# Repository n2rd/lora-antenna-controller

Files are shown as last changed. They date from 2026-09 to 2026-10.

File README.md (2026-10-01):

# LoRa Antenna Controller

A professional-grade, bidirectional LoRa-based antenna controller system for remote antenna selection and telemetry monitoring. This system is designed for amateur radio operators managing multi-element antennas.

## System Overview

The LoRa Antenna Controller consists of two components working together:

### **Shack Unit** (`lora_shack_unit/`)
- Mounted in the shack for local operator control
- Controls antenna direction via 8 pushbuttons
- Displays real-time antenna status and telemetry on OLED screen
- Supports PTT button for requesting power/SWR measurements
- Serial interface for computer-based remote control
- Hardware: Heltec WiFi LoRa 32 V3 (ESP32-S3) + SSD1306 OLED + MCP23017 GPIO expander

### **Field Unit** (`lora_field_unit/`)
- Mounted at antenna site for remote relay control
- Drives 6-channel relay module to switch antenna elements
- Monitors voltage, current, and reverse power with INA219 + ADC
- Reports telemetry back to controller via LoRa
- Supports both RemoteQTH (8-direction) and Comtek (4-direction) antenna configurations
- Hardware: Heltec WiFi LoRa 32 V3 (ESP32-S3) + INA219 power monitor

## Key Features

- **Wireless Communication**: 915 MHz LoRa (SX1262 radio)
- **Protocol**: Hygain DCU-1 compatible azimuth rotator protocol
- **Antenna Configurations**: 8-direction (RemoteQTH) or 4-direction (Comtek) via compile-time selection
- **Telemetry**: Comprehensive monitoring of voltage, current, RSSI, and reverse power
- **Reliability**: RadioLib with automatic packet retry and acknowledgment
- **Power Monitoring**: Real-time voltage/current on bus and MCU rails

## Hardware

Both units use Heltec WiFi LoRa 32 V4 boards (ESP32-S3 with SX1262).  The field-unit does not need a display.:
- **Microcontroller**: ESP32-S3 (240 MHz dual-core)
- **LoRa Radio**: SX1262 (915 MHz)
- **Power**: USB-C (microcontroller) + external 12-13.8V supply (field unit)

See individual README files in each folder for detailed hardware specifications, pinouts, and configuration options.

## Getting Started

For detailed information, see:
- **Shack Unit**: [lora_shack_unit/README.md](lora_shack_unit/README.md)
- **Field Unit**: [lora_field_unit/README.md](lora_field_unit/README.md)

Both directories contain the complete firmware code, documentation, and build instructions using PlatformIO.

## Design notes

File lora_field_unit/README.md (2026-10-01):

# LoRa Field Unit for Antenna Control

Professional-grade LoRa-based remote antenna rotator control with multi-element switching and comprehensive telemetry monitoring.

## Overview

This project implements the **Field Unit** that controls antenna rotation relays in a RemoteQTH or Comtek 4SQ antenna phasing unit. The field unit is mounted at the antenna site and provides:

- **8-direction antenna switching** (N, NE, E, SE, S, SW, W, NW) - RemoteQTH configuration
- **4-direction antenna switching** (N, E, S, W) - Comtek configuration (via compile-time selection)
- **6 independent relay outputs** for element switching
- **Real-time voltage and current monitoring** via INA219
- **Reverse power (SWR) measurement** via 12-bit ADC
- **Bidirectional LoRa communication** at 915 MHz
- **Complete telemetry reporting** (voltage, current, RSSI, etc.)

The remote unit operates in conjunction with the [lora_shack_unit](../lora_shack_unit) controller unit, receiving antenna rotation commands and returning extensive telemetry data.

## Hardware Requirements

### Field Unit
- **Microcontroller and LoRa Radio**: Heltec WiFi LoRa 32 V4 (ESP32-S3, SX1262)
- **Relay Module**: 6-channel relay interface module (GPIO controlled)
- **Voltage/Current Monitor**: Adafruit INA219 (I2C, address 0x40)
- **ADC Input**: Analog input from reverse power detector (12-bit, 0-3.3V on GPIO6)

### Required Libraries
- `jgromes/RadioLib@^7.0.0` - LoRa radio driver (SX1262)
- `adafruit/Adafruit INA219@^1.2.3` - Power monitoring

## Hardware Design

PCB design files and bill of materials are available in the `hardware/` folder:

- **[Gerber Files](hardware/field_gerbers/)** - Complete PCB design for manufacturing
  - Ready for submission to PCB manufacturers (JLCPCB, OSHPark, etc.)
  - Includes all layers for 2-layer board construction

- **[Bill of Materials (BOM)](hardware/field_bom.csv)** - Complete component list
  - CSV format compatible with most electronics suppliers
  - Includes part numbers, quantities, and reference designators
  - Use for ordering components from Digi-Key, Mouser, etc.

3D-printable enclosure files are available in the `STL/` folder:

- **[3D Enclosure Files](STL/)** - Ready-to-print case for the field unit
  - `Top.stl` - Top enclosure piece
  - `Bottom.stl` - Bottom enclosure piece
  - Recommended for SLA or FDM 3D printers with support material
  - Print orientation and parameters depend on your printer

### Assembly and Manufacturing

1. Download gerber files and submit to your PCB manufacturer
2. Review the BOM CSV file and order components
3. Use a reflow oven or soldering iron for assembly
4. Download and 3D print the STL files for the enclosure
5. See individual component datasheets for proper solder joint techniques

## Pinouts

### LoRa Radio (SX1262 via SPI)
| Function | Pin | Notes |
|---|-----|---|
| Radio CS | 8 | Chip Select |
| Radio BUSY | 13 | Busy signal |
| Radio RST | 12 | Reset |
| Radio DIO1 | 14 | Interrupt (IRQ) |
| RF FEM EN | 2 | RF Front-End Module Enable |
| RF FEM PA | 46 | RF Power Amplifier Enable |
| SPI SCLK | 12 | (Hardware SPI) |
| SPI MOSI | 11 | (Hardware SPI) |
| SPI MISO | 13 | (Hardware SPI) |

### Relay Outputs
| Relay | Pin | Purpose |
|---|-----|---|
| Relay 1 | 3 | Element 1 |
| Relay 2 | 4 | Element 2 |
| Relay 3 | 5 | Element 3 |
| Relay 4 | 33 | Element 4 |
| Relay 5/6 | 47 | Parallel relay group |
| Relay 7/8 | 48 | Parallel relay group |

### Sensors
| Function | Pin | Notes |
|---|-----|---|
| Rev Power ADC | 6 | Analog reverse power input (ADC1 Ch6) |
| I2C SDA | 41 | I2C for INA219 |
| I2C SCL | 42 | I2C for INA219 |
| Status LED | 35 | Onboard LED (LED_BUILTIN) |
| VEXT EN | 36 | Peripheral power control (active LOW) |

## Features

### Relay Configuration Tables

#### RemoteQTH - 8-Direction Configuration

| Direction | Angle | Relay Pattern | Purpose |
|---|---|---|---|
| N | 000° | 0,0,0,0,0,0 | All elements parallel |
| NE | 045° | 0,0,1,1,0,1 | Northeast phasing |
| E | 090° | 1,1,1,1,1,1 | All elements series |
| SE | 135° | 0,1,1,0,0,1 | Southeast phasing |
| S | 180° | 0,0,0,0,1,1 | Reverse configuration |
| SW | 225° | 1,1,0,0,0,1 | Southwest phasing |
| W | 270° | 1,1,1,1,0,0 | West switching |
| NW | 315° | 1,0,0,1,0,0 | Northwest phasing |

#### Comtek - 4-Direction Configuration

| Direction | Angle | Relay Pattern | Purpose |
|---|---|---|---|
| N/NE | 000-045° | 0,0,... | Pattern A |
| E/SE | 090-135° | 1,0,... | Pattern B |
| S/SW | 180-225° | 0,1,... | Pattern C |
| W/NW | 270-315° | 1,1,... | Pattern D |

**Note**: Comtek uses only 2 primary relays for 4 directions. Angles within each quadrant are mapped to the closest cardinal direction.

### Protocol

- **DCU-1 compatible** aperture rotator protocol
- **Position command**: `AP1###\r` where `###` is azimuth (000-359)
- **Position query**: `AI1;` or `AM1` requests current position
- **Power request**: Single `V` character requests reverse power telemetry
- **Auto-acknowledgment** with RadioHead reliable datagram

### Telemetry Data

Each reply packet contains complete antenna and power measurements:

```
+-------+-----+-----+-----+-----+-----+
| Type  | Dir | RSSI | Volt| Curr| Batt|
| (1)   | (3) | (5)  | (5) | (3) | (4) |
+-------+-----+-----+-----+-----+-----+
;       045   r-095 v13800 i0500 b4200
V       1250.6
```

**Position Reply Format**: `;XYZrRRRRvVVVVViIIIbBBBB`
- `;` - Position reply marker
- `XYZ` - 3-digit azimuth (000-359)
- `rRRRR` - RSSI (e.g., r-095 for -95 dBm)
- `vVVVVV` - Bus voltage in mV (e.g., v13800 = 13.8V)
- `iIII` - Bus current in mA (e.g., i0500 = 500mA)
- `bBBBB` - MCU supply voltage in mV

**Power Reply Format**: `VPPPPPP`
- `V` - Power reply marker
- `PPPPPP` - Reverse power in watts (6 chars, e.g., 1250.6W)

## Configuration

All hardware parameters are defined in `include/config.h`:

### Antenna Controller Type Selection

The phaser unit supports **two antenna controller types** selectable at compile time:

#### RemoteQTH (8-Direction) - DEFAULT
- Supports 8 antenna directions: N, NE, E, SE, S, SW, W, NW
- Most flexible configuration
- Recommended for full-featured antenna control

#### Comtek (4-Direction)
- Supports 4 main directions with combined angles
- Simpler relay switching
- Compatible with older Comtek rotators

## Quick Start with Pre-Built Binaries

Pre-compiled binaries are available in the [GitHub Releases](https://github.com/your-org/lora-antenna-controller/releases) for both RemoteQTH and Comtek configurations:

- `lora_field_unit_remoteqth.bin` - 8-direction RemoteQTH antenna controller (default)
- `lora_field_unit_comtek.bin` - 4-direction Comtek antenna controller

### Flashing with ESP Web Tools (Recommended - No Installation Required!)

1. **Download the binary** from [Releases](https://github.com/your-org/lora-antenna-controller/releases)

2. **Connect your Heltec device** via USB cable

3. **Open ESP Web Tools** in your browser:
   - Visit: https://esp.huhn.me/
   - Or use: https://web.esphome.io/

4. **Click "Connect"** and select your device's serial port from the popup

5. **Select the binary file**:
   - Click "Choose file" and select `lora_field_unit_remoteqth.bin` or `lora_field_unit_comtek.bin`

6. **Click "Program"** and wait for the flash to complete

7. **Done!** The device will reboot automatically

That's it! No command line needed.

### Building for Different Antenna Types using PlatformIO

**For RemoteQTH (default, 8-direction):**
```bash
cd lora_field_unit
pio run -t upload -e heltec_wifi_lora_32_V3
```

**For Comtek (4-direction):**
```bash
cd lora_field_unit
pio run -t upload -e heltec_wifi_lora_32_V3 -D ANTENNA_CONFIG=2
```

### Configuration at Compile Time

The antenna type is controlled via the `ANTENNA_CONFIG` define in `include/config.h`:

```cpp
#define ANTENNA_CONFIG ANTENNA_REMOTEQTH  // 1 = RemoteQTH
#define ANTENNA_CONFIG ANTENNA_COMTEK     // 2 = Comtek
```

Or via `platformio.ini`:

```ini
; RemoteQTH (default)
build_flags = -D ANTENNA_CONFIG=1

; Comtek
build_flags = -D ANTENNA_CONFIG=2
```

### Radio and Hardware Parameters

```cpp
#define SX1262_FREQ 915.0         // LoRa frequency
#define MY_ADDRESS 212            // This remote unit's address
#define CTRL_ADDRESS 211          // Controller unit address
#define INA219_I2C_ADDRESS 0x40   // Power monitor I2C address
#define REV_POWER_PIN 6           // Reverse power ADC pin
#define REV_POWER_CONVERSION_FACTOR 371.71F // ADC to power conversion
```

## Building and Uploading

### With PlatformIO

```bash
cd lora_field_unit

# Build the project
pio run -e heltec_wifi_lora_32_V3

# Upload to device
pio run -t upload -e heltec_wifi_lora_32_V3

# Monitor serial output (115200 baud)
pio device monitor -b 115200
```

### With Arduino IDE

1. Install ESP32 board definitions (via Boards Manager: "esp32")
2. Install Heltec board support (https://github.com/Heltec-Aaron-Lee/WiFi_Kit_series)
3. Select "Heltec WiFi LoRa 32(V3)" as board
4. Install required libraries:
   - RadioLib (jgromes/RadioLib)
   - Adafruit INA219
5. Upload sketch

## Installation

### At Antenna Site
1. Mount Feather M0 in weatherproof enclosure
2. Connect LoRa antenna to SMA connector
3. Wire relay module outputs to antenna controller
4. Connect INA3221 power monitor to supply bus
5. Connect reverse power detector to ADC input (A2)
6. Connect relay coils to their respective elements

### Weatherproofing
- Mount PCB in IP67 rated enclosure
- Apply conformal coating to PCB (recommended for outdoor use)
- Use shielded SMA connector for antenna
- Add moisture-absorbing desiccant packet inside enclosure

## Operation

### Startup Sequence
1. Serial output shows initialization messages
2. Radio configured and tested
3. Relays initialized to safe state (North position)
4. Onboard LED flashes to confirm ready state

### Command Processing
1. Controller sends antenna direction command
2. Phaser receives and parses command
3. Relays configured for requested direction
4. Sensors read (voltage, current, power)
5. Reply packet transmitted back to controller
6. LED flashes once per successful transmission

### Telemetry Measurements

**Voltage Monitoring (INA219)**:
- Bus voltage measurement
- MCU supply rail monitoring
- Shunt resistor: 0.10Ω

**Current Measurement**:
- Bus current range: ±3.2A (with 0.10Ω shunt)
- Calibration: Via INA219 library

**Reverse Power ADC**:
- 12-bit resolution (0-1023 counts via analogReadMilliVolts())
- Input range: 0-3.3V
- Sampling: 10-sample average with 3-top averaging
- Conversion factor: 371.71 (calibrated for detector voltage)

## Error Handling

- **Radio init failed**: Continuous LED blink, halts operation
- **No INA219**: Log error to serial, continue with zero telemetry
- **Invalid command**: Log warning, return current position
- **Send failed**: Log error, await next command

### Protocol Compliance

Implements **Yaesu DCU-1** rotator protocol for maximum compatibility:

- **Command set**: AP1###, AI1, V, ;
- **ASCII protocol**: Easy integration with existing systems
- **Binary telemetry**: Optional for future enhancement
- **Reliable delivery**: RadioHead datagram with automatic retry
- **Angle parsing**: Auto-maps requested angle to nearest supported direction

#### Angle-to-Direction Mapping

**RemoteQTH** - Direct 45° increments:
- 000° → N, 045° → NE, 090° → E, 135° → SE, etc.

**Comtek** - Quadrant-based (can accept any angle, maps to nearest quadrant):
- 000-045° → N/NE pattern
- 090-135° → E/SE pattern
- 180-225° → S/SW pattern
- 270-315° → W/NW pattern

Both configurations accept the full 0-359° angle range for maximum compatibility with existing controllers.

## Troubleshooting

### No response from phaser
1. Check LoRa antenna connector is secure
2. Verify power supply is connected (LED should indicate operation)
3. Check address settings in `config.h` match controller
4. Monitor serial output for error messages

### Relays not switching
1. Check relay module power supply (typically 12V, 1A+)
2. Verify relay coil winding voltage matches supply
3. Check GPIO pins are correctly wired to relay inputs
4. Test relay operation with DC power supply directly

### Telemetry not updating
1. Check INA219 I2C connections
3. Check address 0x40 is correct for your INA219
4. Monitor serial output for I2C init errors

### ADC reverse power readings are wrong
1. Check ADC input voltage is 0-3.3V range
2. Verify voltage divider in reverse power detector
3. Adjust `REV_POWER_CONVERSION_FACTOR` in config.h
4. Calibrate against known SWR bridge readings

## License

This project is licensed under the MIT License - see [LICENSE](LICENSE) file for details.

## Contributing

Contributions are welcome! Please follow these guidelines:

1. Fork the repository
2. Create a feature branch (`git checkout -b feature/AmazingFeature`)
3. Commit your changes (`git commit -m 'Add some AmazingFeature'`)
4. Push to the branch (`git push origin feature/AmazingFeature`)
5. Open a Pull Request

## References

- [RadioLib Documentation](https://jgromes.github.io/RadioLib/)
- [Yaesu DCU-1 Protocol](https://www.yaesu.com)
- [Heltec WiFi LoRa 32 V3 Documentation](https://docs.heltec.org/en/node/esp32/dev-board/lora/index.html)
- [Heltec GitHub](https://github.com/Heltec-Aaron-Lee/WiFi_Kit_series)
- [SX1262 LoRa Module Datasheet](https://www.semtech.com/products/wireless-rf/lora-transceivers/sx1262)
- [Adafruit INA219 Library](https://github.com/adafruit/Adafruit_INA219)
- [INA219 Power Monitor Datasheet](https://www.ti.com/lit/ds/symlink/ina219.pdf)

## Authors

- Rajiv Dewan, N2RD. rmdewan@gmail.com

## Acknowledgments

- Adafruit Industries for excellent hardware and libraries
- Mike McCauley for RadioHead library
- Hygain for DCU-1 protocol specification

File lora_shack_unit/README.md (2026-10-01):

# LoRa Antenna Controller - Shack Unit

Professional-grade LoRa-based antenna azimuth controller for remote antenna selection and telemetry monitoring from the shack.

## Overview

This project implements a **controller unit** that wirelessly controls antenna rotation via LoRa radio. The controller is mounted in the shack and provides:

- **8-direction antenna control** (N, NE, E, SE, S, SW, W, NW)
- **Real-time telemetry display** on SSD1306 OLED screen
- **Button interface** for quick direction selection (via MCP23017 GPIO expander)
- **PTT button** for requesting reverse power / telemetry
- **Serial interface** for computer control
- **Link quality monitoring** with RSSI display
- **Bidirectional LoRa communication** at 915 MHz

The controller works in tandem with the [lora_field_unit](../lora_field_unit) remote unit, which drives the relay switches to select antenna elements.

## Hardware Requirements

### Controller Unit
- **Microcontroller and LoRa Radio**: Heltec WiFi LoRa 32 V3 (ESP32-S3, SX1262)
- **OLED Display**: SSD1306 128×64 pixel display (built-in, on dedicated I2C bus)
- **GPIO Expander**: MCP23017 I2C to digital I/O (for buttons and LEDs)
- **Buttons**: 8 pushbuttons for direction selection (on MCP23017)
- **LEDs**: 8 LEDs for direction indication (on MCP23017)
- **PTT Switch**: Momentary pushbutton (GPIO3 on ESP32)

### Required Libraries
- `jgromes/RadioLib@^7.0.0` - LoRa radio driver (SX1262)
- `adafruit/Adafruit MCP23017 Arduino Library@^2.3.2` - GPIO expander
- `olikraus/U8g2@^2.35.9` - OLED display driver (SSD1306)

## Hardware Design

PCB design files and bill of materials are available in the `hardware/` folder:

- **[Gerber Files](hardware/shack_gerbers/)** - Complete PCB design for manufacturing
  - Ready for submission to PCB manufacturers (JLCPCB, OSHPark, etc.)
  - Includes all layers for 2-layer board construction

- **[Bill of Materials (BOM)](hardware/shack_bom.csv)** - Complete component list
  - CSV format compatible with most electronics suppliers
  - Includes part numbers, quantities, and reference designators
  - Use for ordering components from Digi-Key, Mouser, etc.

3D-printable enclosure files are available in the `STL/` folder:

- **[3D Enclosure Files](STL/)** - Ready-to-print case for the shack controller
  - `Top.stl` - Top enclosure piece
  - `Bottom.stl` - Bottom enclosure piece
  - `Bracket.stl` - Mount bracket for desk/shelf mounting
  - Recommended for SLA or FDM 3D printers with support material
  - Print orientation and parameters depend on your printer

### Assembly and Manufacturing

1. Download gerber files and submit to your PCB manufacturer
2. Review the BOM CSV file and order components
3. Use a reflow oven or soldering iron for assembly
4. Download and 3D print the STL files for the enclosure and bracket
5. See individual component datasheets for proper solder joint techniques

## Pinouts

### LoRa Radio (SX1262 via SPI)
| Function | Pin | Notes |
|---|-----|---|
| Radio CS | 8 | Chip Select |
| Radio BUSY | 13 | Busy signal |
| Radio RST | 12 | Reset |
| Radio DIO1 | 14 | Interrupt (IRQ) |
| RF FEM EN | 2 | RF Front-End Module Enable |
| RF FEM PA | 46 | RF Power Amplifier Enable |
| SPI SCLK | 12 | (Hardware SPI) |
| SPI MOSI | 11 | (Hardware SPI) |
| SPI MISO | 13 | (Hardware SPI) |

### Display and I2C
| Function | Pin | Notes |
|---|-----|---|
| OLED SDA | 17 | I2C1 (built-in display) |
| OLED SCL | 18 | I2C1 (built-in display) |
| OLED RST | 21 | Reset pin |
| MCP SDA | 41 | I2C (external GPIO expander) |
| MCP SCL | 42 | I2C (external GPIO expander) |

### Buttons and User Input
| Function | Pin | Notes |
|---|-----|---|
| PTT Button | 3 | GPIO3, INPUT_PULLUP, active LOW |
| Direction Buttons | MCP23017 0-7 | 8 buttons on GPIO expander ports A |
| Direction LEDs | MCP23017 8-15 | 8 LEDs on GPIO expander ports B |

### Power and Control
| Function | Pin | Notes |
|---|-----|---|
| Status LED | 35 | Onboard LED (LED_BUILTIN) |
| VEXT EN | 36 | Peripheral power control (active LOW) |

## Features

### Protocol
- **DCU-1 compatible** aperture command format
- **Position format**: `AP1###\r` where `###` is azimuth (000-359)
- **PTT format**: Single character `V` requests telemetry
- **Automatic acknowledgment** with RadioHead reliable datagram

### Display Output
Shows real-time antenna telemetry:
```
Rev 12.5 W
RSSI: -095 dBm
Pos: 045
Dir: NE
```

### Serial Interface
- Baud rate: **115200** (USB CDC on ESP32-S3)
- Can accept direction names: `N`, `NE`, `E`, `SE`, `S`, `SW`, `W`, `NW`
- Can accept angle values: `0`, `45`, `90`, `135`, `180`, `225`, `270`, `315`

### User Interactions
1. **Push buttons (0-7)**: Select antenna direction, sends command immediately
2. **PTT button**: Request reverse power telemetry from remote shack
3. **Serial input**: Remote computer control via RS-232 interface

## Configuration

All hardware pins and protocol parameters are defined in `include/config.h`:

```cpp
#define SX1262_FREQ 915.0       // LoRa frequency
#define MY_ADDRESS 211          // This controller's address
#define DEST_ADDRESS 212        // Remote field unit address
#define MCP_I2C_ADDRESS 0x20    // MCP23017 I2C address
#define OLED_I2C_ADDRESS 0x3C   // SSD1306 OLED I2C address
#define PTT_PIN 3               // PTT button input (GPIO3)
```

## Quick Start with Pre-Built Binaries

Pre-compiled binaries are available in the [GitHub Releases](https://github.com/your-org/lora-antenna-controller/releases):

- `lora_shack_unit.bin` - Complete shack controller unit firmware

### Flashing with ESP Web Tools (Recommended - No Installation Required!)

1. **Download the binary** from [Releases](https://github.com/your-org/lora-antenna-controller/releases)

2. **Connect your Heltec device** via USB cable

3. **Open ESP Web Tools** in your browser:
   - Visit: https://esp.huhn.me/
   - Or use: https://web.esphome.io/

4. **Click "Connect"** and select your device's serial port from the popup

5. **Select the binary file**:
   - Click "Choose file" and select `lora_shack_unit.bin`

6. **Click "Program"** and wait for the flash to complete

7. **Done!** The device will reboot automatically

That's it! No command line needed.

## Building and Uploading

### With PlatformIO (Recommended)

```bash
cd lora_shack_unit

# Build the project
pio run -e heltec_wifi_lora_32_V3

# Upload to device
pio run -t upload -e heltec_wifi_lora_32_V3

# Monitor serial output (115200 baud)
pio device monitor -b 115200
```

### With Arduino IDE

1. Install ESP32 board definitions (via Boards Manager: "esp32")
2. Install Heltec board support (https://github.com/Heltec-Aaron-Lee/WiFi_Kit_series)
3. Select "Heltec WiFi LoRa 32(V3)" as board
4. Install required libraries:
   - RadioLib (jgromes/RadioLib)
   - U8g2 (olikraus/U8g2)
   - Adafruit MCP23017 Arduino Library
5. Upload sketch

## Troubleshooting

### No communication with field unit
1. Check LoRa antenna is properly connected to SMA connector
2. Test radio with debug output enabled (`#define DEBUG 1` in config.h)
3. Check address settings in `config.h` match field unit (MY_ADDRESS=211, DEST_ADDRESS=212)
4. Verify frequency matches: 915.0 MHz

### Display not showing anything
1. Check OLED display is properly seated
2. Verify I2C address is 0x3C (SSD1306)
3. Enable debug output to monitor I2C initialization errors

### Buttons not responding
1. Check MCP23017 is properly seated on breadboard or module
2. Verify I2C address matches config (0x20 default)
3. Check button wiring to MCP pins (should be between pin and GND)
4. Verify MCP I2C address via I2C scanner if issues persist

### PTT button not working
1. Verify GPIO3 is not being used elsewhere
2. Check button wiring (pin 3 to GND for activation)
3. Ensure INPUT_PULLUP is enabled
4. Test with serial debug enabled

### Startup Sequence
1. Serial output shows initialization messages
2. Radio configured and tested
3. Display shows "READY!"
4. Direction LED turns on (matches current antenna position)

### Normal Operation
1. Press a direction button to rotate antenna
2. LED blinks to confirm command transmission
3. Display updates with current direction and telemetry
4. Press PTT to request reverse power reading
5. Display shows reverse power reading from remote unit

### Error Handling
- **Radio init failed**: LED blinks continuously
- **No reply from phaser**: "No Reply!" displays on OLED
- **Send failed**: "Send Failed!" displays on OLED

## Protocol Details

### Command Types

| Command | Format | Response | Purpose |
|---|---|---|---|
| Set direction | AP1###\r | ;XYZr... | Set antenna azimuth and execute |
| Position query | I1; | ;XYZr... | Request current antenna position |
| Power query | V | VPPPPPP | Request reverse power reading |

### Telemetry Data Returned

Position reply includes:
- Antenna azimuth (000-359°)
- Transmit RSSI (signal strength out, dBm)
- Reverse power measurement (W)
- Bus voltage and current
- MCU supply voltage

## References

- [RadioLib Documentation](https://jgromes.github.io/RadioLib/)
- [Yaesu DCU-1 Rotator Protocol](https://www.yaesu.com)
- [Heltec WiFi LoRa 32 V3 Documentation](https://docs.heltec.org/en/node/esp32/dev-board/lora/index.html)
- [Heltec GitHub](https://github.com/Heltec-Aaron-Lee/WiFi_Kit_series)
- [SX1262 LoRa Module Datasheet](https://www.semtech.com/products/wireless-rf/lora-transceivers/sx1262)
- [MCP23017 I/O Expander Datasheet](https://ww1.microchip.com/en-US/product/mcp23017)
- [U8g2 Library](https://github.com/olikraus/u8g2)
- [Adafruit MCP23017 Arduino Library](https://github.com/adafruit/Adafruit-MCP23017-Arduino-Library)

## Authors

- Rajiv Dewan, N2RD rmdewan@gmail.com

## Acknowledgments

- Adafruit Industries for excellent hardware and libraries
- RadioHead Library by Mike McCauley
- Yaesu Corporation for the DCU-1 protocol specification

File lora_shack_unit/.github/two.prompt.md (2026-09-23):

There are two differnt commands that the controller sends to the phaser: a direction command a power command.

The responses from the phaser are different for the two commands.  

The display shows the results of both the commands.  When displaying the results of the direction command, it shoudl reuse the previous displayed value of the power command.  And vice versa, when displaying the results of the power command, it should reuse the previous displayed value of the direction command.

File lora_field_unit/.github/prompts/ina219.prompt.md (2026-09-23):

I want to transition from using the INA3221 sensor to the INA219 sensor for my project. Can you help me with the necessary changes I need to make in my code and hardware setup to accommodate this transition?

The INA3221 is a multiport device and I was using it to measure (1) the bus voltage and current and (2) mcu voltage and current. 

INA 219 is a single channel device.  I will only be measuring bus voltage and current.  I will drop the measurement of mcu voltage and current.  Also, this will not be sent in the payload to the server.  I will only be sending bus voltage and current in the payload.

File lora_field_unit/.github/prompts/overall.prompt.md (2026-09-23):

I have a pair of related projects: lora_phaser_heltec and lora_cont_heltec.  They communicate with each other using LoRa.  

The lora_cont_heltec project is the controller.  It accepts input from the buttons and USB serial port and sends commands using lora to lora_phaser_heltec ih the field.

The lora_phaser_heltec processes the commands and sends a packet of information back to the controller.

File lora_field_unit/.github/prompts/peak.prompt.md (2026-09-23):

I want improve the reverse power measurement as the RF power is applied in pulses as short as 24 mS (morse code dit at 50WPM).  Here are some ideas:

1.  Use the calibrated ADC measurement on ESP32-S3 to measure the reverse power more accurately.  On the ESP32S3 this is done using analogReadMilliVolts() instead of analogRead().  This will give a more accurate measurement of the voltage on the reverse power pin, which can be used to calculate the reverse power more accurately.
2. There is a voltage divider and to adjust for this we need to multiply the measured voltage by 169.86. This will be the new calibration factor for the reverse power measurement.
3. Since the power is pulsed, averaging is not helpful.  An yet there is a lot of noise in the measurement. We need to find a statistic to get a better estimate of the peak without the noise.  What would be a good method?

One approach is the following:
Make 10 measurements, 10mS apart.  Take the average of just the top 3 values.  This will give us a better estimate of the peak power while reducing the impact of noise.  The 10mS interval is chosen to capture the short pulses of RF power, and averaging the top 3 measurements helps to mitigate any outliers caused by noise.

Any other ideas?

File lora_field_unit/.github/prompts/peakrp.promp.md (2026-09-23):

The phaser sends back peak reverse power to the controller.  

I would like to implement a peak-hold feature for this value.

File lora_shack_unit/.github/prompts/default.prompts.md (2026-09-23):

When the unit boots up, it should default to DIR_NE and that LED should be lit.  Instead, it seems to go an random state (different one each time).This is likely an initialization error that needs to be fixed.

After a button is pressed, the controller waits for a reply and then uses the direction in the apply to do the following:

1. It should blink that LED that corresponds to the reply twice and then leaves it lit. (0.5 sec cycle for blinking)
2. It should show the direction in the reply on the LED.

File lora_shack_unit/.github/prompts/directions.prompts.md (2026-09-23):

Somehow, my files have gotten the directions, and numbering mixed up.

Here is what I want:
// inits for the controller unit
// NE has all relays off and is perfect for default
int last_button = 0;  //initialize last button pressed, default to NE

//directions
#define NE 0
#define E  1
#define SE 2
#define S  3
#define SW 4
#define W  5
#define NW 6
#define N  7

int direction = 0;  //current position

And in the phaser:

//array of relay status for each position
boolean relay[8][6]{ //remoteqth 
  {LOW,  LOW,  LOW,  LOW,  LOW,  LOW},  //NE 0
  {LOW,  LOW,  HIGH, HIGH, LOW,  HIGH}, //E 1
  {HIGH, HIGH, HIGH, HIGH, HIGH, HIGH}, //SE 2
  {LOW,  HIGH, HIGH, LOW,  LOW,  HIGH}, //S 3
  {LOW,  LOW,  LOW,  LOW,  HIGH, HIGH}, //SW 4
  {HIGH, HIGH, LOW,  LOW,  LOW,  HIGH}, //W 5
  {HIGH, HIGH, HIGH,  HIGH, LOW,  LOW},  //NW 6
  {HIGH, LOW,  LOW,  HIGH, LOW,  LOW}   //N 7
};

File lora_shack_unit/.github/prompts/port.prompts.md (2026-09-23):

I want to port the project lora_cont_2 from using Adafruit Feather M0 with RFM95 LoRa radio to a Heltec V4.  Here are some details for the porting:

1.  I have placed a default platformio environment in platformio.ini.  It may need some modification, in particular to use the same LoRa libray as the Adafruit version.

2. We will use the pins as defined the variants.h file (part of heltec library)

3. The built in display uses I2C, with pin 17 for SDA and pin 18 for SCL.  These are already defined in the variants.h file.  It display is 128 x 64.  I would like to use it in the portrait orientation.  It uses the SSD1306 driver.

4. We will use the default I2C already defined in variants.h SDA (4) and SCL (3) pins for conntecting to the MCP23017 GPIO expander. 

5.  We will use GPIO3 (ADC1: Channel 2) cofigured with PULLUP to read the PTT status.  It is active low.

6.  I want to be able to use either board.  So we may have to put compile time conditionals for each board.

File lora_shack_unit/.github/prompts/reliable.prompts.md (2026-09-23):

Lightweight ACK Flow

If you want to keep a simple peer-to-peer (P2P) setup, you can manually reproduce a basic reliable datagram pattern using RadioLib's non-blocking/interrupt methods. The library maintainer officially recommends avoiding blocking loops and instead structuring a Ping-Pong state machine:Keep both nodes in continuous listen mode by using radio.startReceive().

Sender Transmits: Prepend your data payload with 3 or 4 control bytes (e.g., [Target_ID] [Sender_ID] [Packet_Sequence_Num]). Send using non-blocking transmit, then switch immediately back to listen mode.

Receiver Acknowledges: Upon successfully reading a valid packet, the receiver processes it and immediately replies with a dedicated short ACK packet (e.g., containing the same sequence number) before dropping back to listen mode.

Timeout Handler: On the sender side, if a hardware timer/timeout interrupt triggers before the matching ACK packet is caught, increment an attempt counter and retransmit the packet.

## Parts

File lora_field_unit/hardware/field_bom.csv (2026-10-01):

Reference | Qty | Value | DNP | Exclude from BOM | Exclude from Board | Footprint | Datasheet
A1 | 1 | Adafruit_Feather_M0_RFM69HCW_Packet_Radio |  |  |  | Module:Adafruit_Feather_M0_RFM | https://cdn-learn.adafruit.com/downloads/pdf/adafruit-feather-m0-radio-with-rfm69-packet-radio.pdf
C1,C2,C3,C5,C7,C9,C11,C13 | 8 | 220n |  |  |  | Capacitor_SMD:C_1206_3216Metric_Pad1.33x1.80mm_HandSolder
C4,C6,C8,C10,C12,C14 | 6 | 1n |  |  |  | Capacitor_SMD:C_1206_3216Metric_Pad1.33x1.80mm_HandSolder
J1 | 1 | Conn_01x02_Pin |  |  |  | TerminalBlock_4Ucon:TerminalBlock_4Ucon_1x02_P3.50mm_Horizontal
J3 | 1 | Screw_Terminal_01x08 |  |  |  | TerminalBlock:TerminalBlock_MaiXu_MX126-5.0-08P_1x08_P5.00mm
L1 | 1 | T50-43 20t 22swg |  |  |  | Kicad_libs:T50
R1 | 1 | 20K |  |  |  | Resistor_SMD:R_1206_3216Metric_Pad1.30x1.75mm_HandSolder
R2 | 1 | 1K |  |  |  | Resistor_SMD:R_1206_3216Metric_Pad1.30x1.75mm_HandSolder
U1,U2,U3,U4,U5,U6 | 6 | ITS4200S-ME-P |  |  |  | Kicad_libs:SOT-223-3_TabPin4
U7 | 1 |  |  |  |  | Kicad_libs:Adafruit_6062_INA3221
U8 | 1 | BUCK_4739 |  |  |  | Kicad_libs:MODULE_4739

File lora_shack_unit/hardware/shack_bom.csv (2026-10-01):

Reference | Qty | Value | DNP | Exclude from BOM | Exclude from Board | Footprint | Datasheet
D1,D2,D3,D4,D5,D6,D7,D8 | 8 | LED |  |  |  | Kicad_libs:LED_D5.0mm_Clear
J1,J2 | 2 | Conn_01x04_Pin |  |  |  | Connector_JST:JST_XH_B4B-XH-AM_1x04_P2.50mm_Vertical
R1 | 1 | 330 |  |  |  | Resistor_THT:R_Axial_DIN0207_L6.3mm_D2.5mm_P15.24mm_Horizontal
R2,R3,R4,R5,R6,R7,R8 | 7 | 330 |  |  |  | Resistor_THT:R_Axial_DIN0207_L6.3mm_D2.5mm_P10.16mm_Horizontal
SW1,SW2,SW3,SW4,SW5,SW6,SW7,SW8 | 8 | SW_Push |  |  |  | Kicad_libs:SW_Tactile_Straight_KSA0Axx1LFTR
U1 | 1 |  |  |  |  | Kicad_libs:Adafruit_5346_MCP

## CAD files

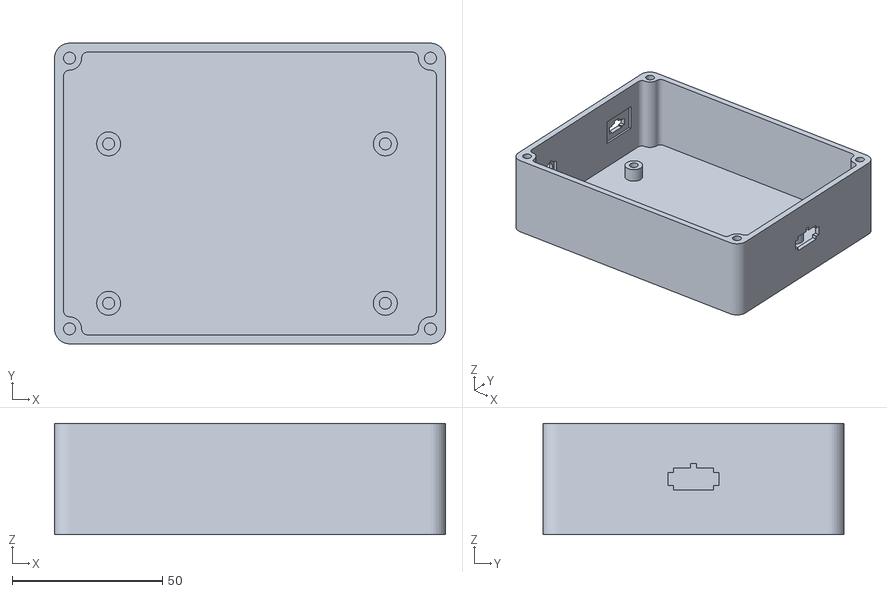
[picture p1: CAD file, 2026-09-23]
lora_field_unit/STL/Bottom.stl
130.0 x 100.0 x 37.0

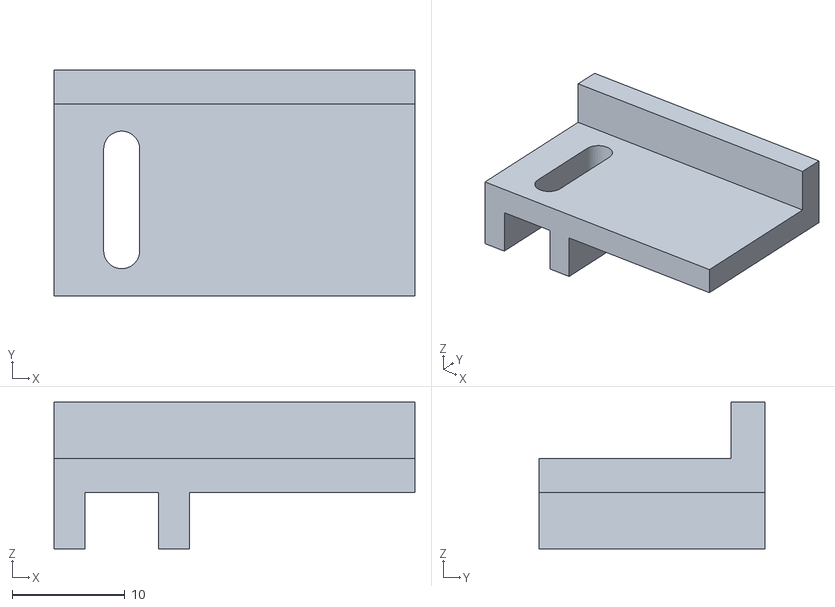
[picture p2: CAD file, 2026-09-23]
lora_shack_unit/STL/Bracket.stl
32.0 x 20.0 x 13.0

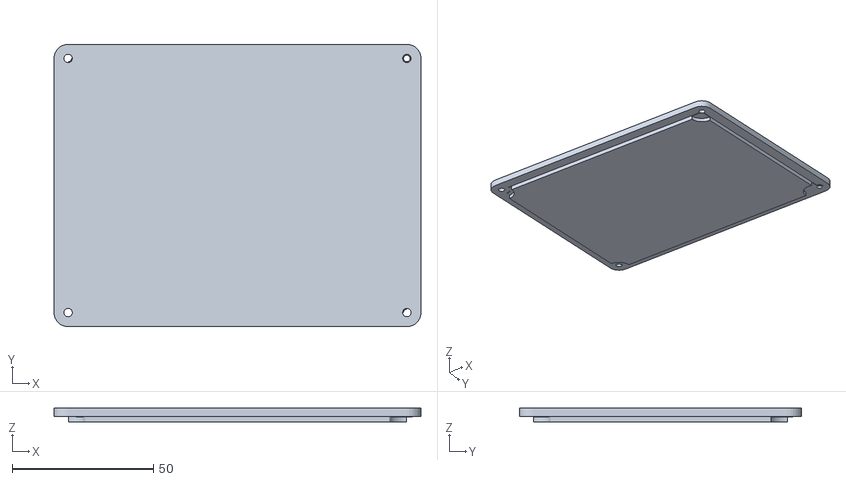
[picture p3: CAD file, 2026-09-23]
lora_field_unit/STL/Top.stl
130.0 x 100.0 x 5.00

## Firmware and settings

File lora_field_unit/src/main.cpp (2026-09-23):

/**
 * @file main.cpp
 * @brief LoRa Antenna Phaser - Remote Antenna Rotator Control (Heltec WiFi LoRa 32 V3)
 *
 * Receives LoRa commands from the controller, drives relay outputs to
 * switch antenna direction, and returns telemetry (position, voltage,
 * current, RSSI, reverse power).
 *
 * Hardware:
 * - Heltec WiFi LoRa 32 V3 (ESP32-S3)
 * - SX1262 LoRa Radio (915 MHz) via RadioLib
 * - 6-channel relay module on GPIO 1-6
 * - Adafruit INA219 on Wire (SDA=41, SCL=42)
 * - ADC input GPIO7 for reverse power (SWR)
 *
 * @author Rajiv Dewan, N2RD
 * @date 2026
 */

// ============================================================================
// INCLUDES
// ============================================================================

#include <Arduino.h>
#include <Wire.h>
#include <SPI.h>
#include <RadioLib.h>
#include <Adafruit_INA219.h>
#include "config.h"
#include "protocol.h"

// ============================================================================
// GLOBAL OBJECTS
// ============================================================================

// RadioLib SX1262: Module(cs, irq, rst, busy)
SX1262 radio = new Module(SX1262_CS, SX1262_INT, SX1262_RST, SX1262_BUSY);

// Current/voltage monitor
Adafruit_INA219 ina219;

// ============================================================================
// APPLICATION STATE
// ============================================================================

int current_direction = DIR_NE;
int target_direction  = DIR_NE;
int bus_voltage_mv    = 0;
int bus_current_ma    = 0;

char    command_buffer[MAX_COMMAND_LEN];
int     command_length = 0;
uint8_t reply_buffer[255];
int     reply_length  = 0;

int16_t packet_count  = 0;

bool have_ina219 = false;   ///< true if INA219 was detected at startup

// ISR flag: set by DIO1 when a LoRa packet arrives
volatile bool packetReceived = false;

// ============================================================================
// FUNCTION PROTOTYPES
// ============================================================================

void init_all_hardware(void);
void set_antenna_direction(int direction);
void measure_sensors(void);
int  read_reverse_power_adc(void);
int  read_bus_voltage(void);
int  read_bus_current(void);
void build_position_reply(int direction);
void build_power_reply(void);
void process_command(void);
void handle_set_direction(int direction);
void handle_position_query(void);
void handle_power_query(void);
int  parse_direction_from_command(void);

// ============================================================================
// INTERRUPT SERVICE ROUTINE
// ============================================================================

void IRAM_ATTR onPacketReceived(void) {
    packetReceived = true;
}

// ============================================================================
// INITIALIZATION
// ============================================================================

void init_all_hardware(void) {
    // Serial — USB CDC on ESP32-S3.
    // Do NOT block on Serial or flush when running without a USB host.
    Serial.begin(115200);
    delay(500);  // Short settle; skip the 5s dot loop when no host is connected
    Serial.println();
    Serial.println("\n========== LoRa Antenna Phaser (Heltec V3) Starting ==========");
    Serial.printf("  CPU: %d MHz, Free heap: %d bytes\n",
                  (int)(F_CPU / 1000000), ESP.getFreeHeap());

    // Enable Vext for external peripherals
    Serial.println("[INIT] Enabling Vext peripheral power...");
    pinMode(VEXT_PIN, OUTPUT);
    digitalWrite(VEXT_PIN, LOW);
    delay(200);
    Serial.println("[INIT] Vext enabled.");

    // LED
    pinMode(LED, OUTPUT);
    digitalWrite(LED, LOW);

    // Relay output pins — default all LOW (relays off)
    pinMode(RELAY_1,  OUTPUT); digitalWrite(RELAY_1,  LOW);
    pinMode(RELAY_2,  OUTPUT); digitalWrite(RELAY_2,  LOW);
    pinMode(RELAY_3,  OUTPUT); digitalWrite(RELAY_3,  LOW);
    pinMode(RELAY_4,  OUTPUT); digitalWrite(RELAY_4,  LOW);
    pinMode(RELAY_56, OUTPUT); digitalWrite(RELAY_56, LOW);
    pinMode(RELAY_78, OUTPUT); digitalWrite(RELAY_78, LOW);

    // Set initial safe direction
    set_antenna_direction(DIR_NE);
    Serial.println("[INIT] Relay outputs configured.");

    // ADC — 12-bit on ESP32-S3
    analogReadResolution(12);
    Serial.println("[INIT] ADC 12-bit resolution set.");

    // External I2C for INA219
    Wire.begin(I2C_SDA, I2C_SCL);

    // RadioLib SX1262 init
    // begin(freq, bw, sf, cr, syncWord, pwr, preambleLen, tcxoVoltage)
    // TCXO on Heltec V3 is 1.8V
    // set FM pins to output and set them high to enable PA on receive and transmit
    pinMode(SX1262_FEM_EN, OUTPUT);
    pinMode(SX1262_FEM_PA, OUTPUT);
    digitalWrite(SX1262_FEM_EN, HIGH);
    digitalWrite(SX1262_FEM_PA, HIGH);

    Serial.printf("[INIT] Starting LoRa radio (CS=%d, INT=%d, RST=%d, BUSY=%d)...\n",
                  SX1262_CS, SX1262_INT, SX1262_RST, SX1262_BUSY);
    int state = radio.begin(SX1262_FREQ, 250.0, 11, 5,
                            RADIOLIB_SX126X_SYNC_WORD_PRIVATE, 22, 8, 1.8);
    if (state != RADIOLIB_ERR_NONE) {
        Serial.printf("[INIT] ERROR: Radio init failed, code %d\n", state);
        while (1) {
            digitalWrite(LED, HIGH); delay(100);
            digitalWrite(LED, LOW);  delay(100);
        }
    }
    // DIO2 drives the RF switch on Heltec V3
    radio.setDio2AsRfSwitch(true);
    // Register ISR for received packets
    radio.setDio1Action(onPacketReceived);
    // Start listening
    radio.startReceive();
    Serial.printf("[INIT] Radio OK: %.1f MHz, SF9, BW125, CR4/7, TX 20 dBm\n",
                  SX1262_FREQ);

    // INA219 current/voltage monitor
    have_ina219 = ina219.begin();
    if (have_ina219) {
        Serial.println("[INIT] INA219 OK.");
    } else {
        Serial.println("[INIT] INA219 not found; telemetry returns zeros.");
    }

    // Initial sensor reading
    measure_sensors();

    Serial.println("[INIT] ========== All systems ready ==========\n");
}

// ============================================================================
// RELAY CONTROL
// ============================================================================

void set_antenna_direction(int direction) {
    if (direction < 0 || direction >= NUM_DIRECTIONS) return;

    digitalWrite(RELAY_1,  RELAY_POSITIONS[direction][0]);
    digitalWrite(RELAY_2,  RELAY_POSITIONS[direction][1]);
    digitalWrite(RELAY_3,  RELAY_POSITIONS[direction][2]);
    digitalWrite(RELAY_4,  RELAY_POSITIONS[direction][3]);
    digitalWrite(RELAY_56, RELAY_POSITIONS[direction][4]);
    digitalWrite(RELAY_78, RELAY_POSITIONS[direction][5]);

    current_direction = direction;
    DEBUG_PRINTF("Antenna direction set to %d (%s deg)\n",
                 direction, DIRECTION_ANGLES[direction]);
}

// ============================================================================
// SENSOR MEASUREMENTS
// ============================================================================

int read_bus_voltage(void) {
    if (!have_ina219) return 0;
    float v = ina219.getBusVoltage_V();
    return (int)round(1000.0f * v);
}

int read_bus_current(void) {
    if (!have_ina219) return 0;
    float c = ina219.getCurrent_mA();
    return (int)round(c);
}

int read_reverse_power_adc(void) {
    int samples[ADC_AVG_COUNT];
    for (int i = 0; i < ADC_AVG_COUNT; i++) {
        samples[i] = analogReadMilliVolts(REV_POWER_PIN);
        delay(ADC_SAMPLE_DELAY);
    }

    // Partial selection sort — move the ADC_TOP_COUNT largest values to front
    for (int i = 0; i < ADC_TOP_COUNT; i++) {
        for (int j = i + 1; j < ADC_AVG_COUNT; j++) {
            if (samples[j] > samples[i]) {
                int tmp   = samples[i];
                samples[i] = samples[j];
                samples[j] = tmp;
            }
        }
    }

    // Average the top ADC_TOP_COUNT values for a noise-robust peak estimate
    long sum = 0;
    for (int i = 0; i < ADC_TOP_COUNT; i++) sum += samples[i];
    int peak_mv = (int)(sum / ADC_TOP_COUNT);

    DEBUG_PRINTF("Reverse power peak avg: %d mV (top %d of %d)\n",
                 peak_mv, ADC_TOP_COUNT, ADC_AVG_COUNT);
    return peak_mv;
}

void measure_sensors(void) {
    bus_voltage_mv = read_bus_voltage();
    bus_current_ma = read_bus_current();
    DEBUG_PRINTF("Bus: %d mV, %d mA\n", bus_voltage_mv, bus_current_ma);
}

// ============================================================================
// REPLY BUILDING
// ============================================================================

void build_position_reply(int direction) {
    reply_length = 0;

    // Position: ";XYZ"
    reply_buffer[reply_length++] = REPLY_PREFIX_POS;
    reply_buffer[reply_length++] = DIRECTION_ANGLES[direction][0];
    reply_buffer[reply_length++] = DIRECTION_ANGLES[direction][1];
    reply_buffer[reply_length++] = DIRECTION_ANGLES[direction][2];

    // RSSI field: "rRRRR"
    char rssi_str[6];
    sprintf(rssi_str, "r%+04d", (int)radio.getRSSI());
    for (int i = 0; rssi_str[i] != '\0'; i++)
        reply_buffer[reply_length++] = rssi_str[i];

    // Bus voltage: "vVVVVV" (5 digits, millivolts)
    char volt_str[8];
    sprintf(volt_str, "v%05d", bus_voltage_mv);
    for (int i = 0; volt_str[i] != '\0'; i++)
        reply_buffer[reply_length++] = volt_str[i];

    // Bus current: "iIII" (3 digits, milliamps)
    char curr_str[6];
    sprintf(curr_str, "i%03d", bus_current_ma);
    for (int i = 0; curr_str[i] != '\0'; i++)
        reply_buffer[reply_length++] = curr_str[i];

    DEBUG_PRINTF("Position reply length: %d\n", reply_length);
}

void build_power_reply(void) {
    reply_length = 0;

    int adc_mv = read_reverse_power_adc();
    // analogReadMilliVolts() returns pin voltage in mV; scale by voltage divider
    // factor then convert to volts: V_actual = adc_mv * 169.86 / 1000
    float rev_voltage = (adc_mv * REV_POWER_CONVERSION_FACTOR) / 1000.0f;
    float rev_power   = (rev_voltage * rev_voltage) / 100.0f;  // P = Vpeak²/(2×Z0) = Vpeak²/100 (Z0=50 Ω, /2 for RMS)

    reply_buffer[reply_length++] = REPLY_PREFIX_PWR;

    char power_str[8];
    dtostrf(rev_power, 6, 1, power_str);
    for (int i = 0; power_str[i] != '\0' && reply_length < (int)sizeof(reply_buffer); i++)
        reply_buffer[reply_length++] = power_str[i];

    DEBUG_PRINTF("Power reply: %.1f W (ADC: %d mV), length: %d\n",
                 rev_power, adc_mv, reply_length);
}

// ============================================================================
// COMMAND PROCESSING
// ============================================================================

int parse_direction_from_command(void) {
    if (command_length < 7) return current_direction;

    // command_buffer[3..5] = azimuth digits, e.g. "045"
    int digit2 = (int)command_buffer[4] - '0';  // middle digit
    switch (digit2) {
        case 0: return DIR_N;
        case 4: return DIR_NE;
        case 9: return DIR_E;
        case 3: return DIR_SE;
        case 8: return DIR_S;
        case 2: return DIR_SW;
        case 7: return DIR_W;
        case 1: return DIR_NW;
        case 6: return DIR_N;   // 360
        default: return current_direction;
    }
}

void handle_set_direction(int direction) {
    Serial.printf("Setting direction to %d (%s deg)\n",
                  direction, DIRECTION_ANGLES[direction]);

    char terminator = command_buffer[command_length - 1];
    if (terminator == CMD_TERMINATOR_CR) {
        set_antenna_direction(direction);
    } else {
        target_direction = direction;
    }

    measure_sensors();
    build_position_reply(current_direction);
}

void handle_position_query(void) {
    DEBUG_PRINTLN("Position query received");
    measure_sensors();
    build_position_reply(current_direction);
}

void handle_power_query(void) {
    DEBUG_PRINTLN("Power report request received");
    measure_sensors();
    build_power_reply();
}

void process_command(void) {
    if (command_length == 0) return;

    DEBUG_PRINTF("Processing command (%d bytes): %s\n",
                 command_length, command_buffer);

    if (command_length == 1) {
        switch (command_buffer[0]) {
            case CMD_TYPE_POWER:
                handle_power_query();
                break;
            case ';':
                DEBUG_PRINTLN("Stop command");
                measure_sensors();
                build_position_reply(current_direction);
                break;
            default:
                Serial.printf("Unknown single-char command: %c\n", command_buffer[0]);
                break;
        }
        return;
    }

    if (command_length == 3) {
        if (command_buffer[1] == CMD_TYPE_INFO_I) {
            handle_position_query();
        } else if (command_buffer[1] == CMD_TYPE_INFO_M) {
            set_antenna_direction(target_direction);
            measure_sensors();
            build_position_reply(current_direction);
        }
        return;
    }

    if (command_length == 7) {
        if (command_buffer[0] == CMD_PREFIX_A &&
            command_buffer[1] == CMD_PREFIX_P &&
            command_buffer[2] == CMD_PREFIX_1) {
            handle_set_direction(parse_direction_from_command());
        } else {
            Serial.println("Malformed 7-byte command");
        }
        return;
    }

    DEBUG_PRINTF("Unexpected command length: %d\n", command_length);
}

// ============================================================================
// MAIN SETUP AND LOOP
// ============================================================================

void setup() {
    init_all_hardware();
}

void loop() {
    if (!packetReceived) {
        delay(5);
        return;
    }
    packetReceived = false;

    // Read received packet
    size_t pkt_len = radio.getPacketLength();
    if (pkt_len == 0 || pkt_len > (size_t)(MAX_COMMAND_LEN - 1)) {
        pkt_len = MAX_COMMAND_LEN - 1;
    }

    int16_t state = radio.readData((uint8_t*)command_buffer, pkt_len);

    if (state != RADIOLIB_ERR_NONE) {
        Serial.printf("ERROR: readData failed, code %d\n", state);
        radio.startReceive();
        return;
    }

    command_length = (int)pkt_len;
    command_buffer[command_length] = '\0';
    packet_count++;

    Serial.printf("Packet #%d [RSSI:%d dBm]: ",
                  packet_count, (int)radio.getRSSI());
    for (int i = 0; i < command_length; i++) Serial.printf("%02X ", (uint8_t)command_buffer[i]);
    Serial.println();

    // Process command and build reply
    reply_length = 0;
    process_command();

    if (reply_length <= 0) {
        Serial.println("No reply to send.");
        radio.startReceive();
        return;
    }

    // Transmit reply (blocking)
    state = radio.transmit(reply_buffer, (size_t)reply_length);
    if (state != RADIOLIB_ERR_NONE) {
        Serial.printf("ERROR: TX reply failed, code %d\n", state);
    } else {
        DEBUG_PRINTF("Reply sent (%d bytes)\n", reply_length);
        digitalWrite(LED, HIGH); delay(10); digitalWrite(LED, LOW);
    }

    // Clear any TX-done interrupt that fired the ISR during transmit,
    // then re-arm receive.
    packetReceived = false;
    radio.startReceive();
}

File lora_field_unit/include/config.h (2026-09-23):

/**
 * @file config.h
 * @brief Configuration and hardware definitions for LoRa Antenna Phaser
 *
 * This file contains all hardware pin definitions, radio configuration,
 * and system constants for the remote phaser unit.
 *
 * Hardware: Heltec WiFi LoRa 32 V3 (ESP32-S3, SX1262)
 * Purpose: Remote antenna rotation control and telemetry
 *
 * @author Rajiv Dewan, N2RD
 * @date 2026
 */

#ifndef CONFIG_H
#define CONFIG_H

// ============================================================================
// RADIO CONFIGURATION
// ============================================================================

/** @brief LoRa radio frequency in MHz */
#define SX1262_FREQ 915.0

/** @brief This phaser unit's address */
#define MY_ADDRESS 212

/** @brief Controller unit's address */
#define CTRL_ADDRESS 211

// Heltec WiFi LoRa 32 V4 — SX1262 radio pins
#define SX1262_CS   8   ///< LoRa NSS (SS)
#define SX1262_RST  12  ///< LoRa RST
#define SX1262_INT  14  ///< LoRa DIO1 (interrupt)
#define SX1262_BUSY 13  ///< LoRa BUSY
#define SX1262_FEM_EN 2 /// < RF FEM enable 
#define SX1262_FEM_PA 46 /// < RF TX/RX PA Enable

// Power and LED
#define LED      35  ///< Onboard LED (LED_BUILTIN)
#define VEXT_PIN 36  ///< Peripheral power control, active LOW

// External I2C bus (Wire) — used for INA219 (SDA=41, SCL=42 from variants.h)
#define I2C_SDA  41  ///< External I2C SDA
#define I2C_SCL  42  ///< External I2C SCL

// ============================================================================
// RELAY CONTROL PINS
// ============================================================================

/** @brief Relay 1 control pin */
#define RELAY_1  3

/** @brief Relay 2 control pin */
#define RELAY_2  4

/** @brief Relay 3 control pin */
#define RELAY_3  5

/** @brief Relay 4 control pin */
#define RELAY_4 33

/** @brief Relay 5/6 parallel output pin */
#define RELAY_56 47

/** @brief Relay 7/8 parallel output pin */
#define RELAY_78 48

// ============================================================================
// SENSOR PINS
// ============================================================================

/** @brief Analog pin for reverse power measurement (ADC1 Ch6, ESP32-S3) */
#define REV_POWER_PIN 6

/** @brief I2C address of INA219 current/voltage monitor */
#define INA219_I2C_ADDRESS 0x40

// ============================================================================
// ANTENNA CONFIGURATION SELECTION
// ============================================================================

/**
 * @brief Antenna controller type selection
 *
 * Choose one of:
 * - ANTENNA_REMOTEQTH (default) - 8-direction RemoteQTH controller
 * - ANTENNA_COMTEK - 4-direction Comtek controller
 *
 * Can be overridden at compile time via platformio.ini:
 * build_flags = -D ANTENNA_COMTEK
 */
#ifndef ANTENNA_CONFIG
    #define ANTENNA_CONFIG ANTENNA_REMOTEQTH
#endif

#define ANTENNA_REMOTEQTH 1
#define ANTENNA_COMTEK 2

// ============================================================================
// ANTENNA DIRECTIONS (8-Direction Enum)
// ============================================================================

/** @brief Antenna direction enumeration */
enum Direction {
    DIR_N  = 0,   /**< North (000°) */
    DIR_NE = 1,   /**< Northeast (045°) */
    DIR_E  = 2,   /**< East (090°) */
    DIR_SE = 3,   /**< Southeast (135°) */
    DIR_S  = 4,   /**< South (180°) */
    DIR_SW = 5,   /**< Southwest (225°) */
    DIR_W  = 6,   /**< West (270°) */
    DIR_NW = 7    /**< Northwest (315°) */
};

/** @brief Direction angles in degrees */
static const char* DIRECTION_ANGLES[] = {
    "000", "045", "090", "135", "180", "225", "270", "315"
};

/** @brief Number of directions */
#define NUM_DIRECTIONS 8

// ============================================================================
// RELAY CONFIGURATION - REMOTEQTH (8-Direction)
// ============================================================================

#if ANTENNA_CONFIG == ANTENNA_REMOTEQTH

/**
 * @brief Relay configuration for RemoteQTH 8-direction controller
 *
 * Each row represents relay states {R1, R2, R3, R4, R5/6, R7/8} for that direction
 */
static const boolean RELAY_POSITIONS[8][6] = {
    {HIGH, LOW,  LOW,  HIGH, LOW,  LOW},  // N  (000°): 0
    {LOW,  LOW,  LOW,  LOW,  LOW,  LOW},  // NE (045°): 1
    {LOW,  LOW,  HIGH, HIGH, LOW,  HIGH}, // E  (090°): 2
    {HIGH, HIGH, HIGH, HIGH, HIGH, HIGH}, // SE (135°): 3
    {LOW,  HIGH, HIGH, LOW,  LOW,  HIGH}, // S  (180°): 4
    {LOW,  LOW,  LOW,  LOW,  HIGH, HIGH}, // SW (225°): 5
    {HIGH, HIGH, LOW,  LOW,  LOW,  HIGH}, // W  (270°): 6
    {HIGH, HIGH, HIGH, HIGH, LOW,  LOW}   // NW (315°): 7
};

#elif ANTENNA_CONFIG == ANTENNA_COMTEK
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

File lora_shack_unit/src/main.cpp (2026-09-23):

/**
 * @file main.cpp
 * @brief LoRa Antenna Controller (Heltec WiFi LoRa 32 V3)
 *
 * Controls antenna azimuth remotely via LoRa from the shack.
 *
 * Features:
 * - 8-direction antenna control (N, NE, E, SE, S, SW, W, NW)
 * - OLED display showing antenna status and telemetry
 * - Button interface for direction selection via MCP23017
 * - PTT input for requesting power/SWR telemetry
 * - Serial interface for manual command entry
 *
 * Hardware:
 * - Heltec WiFi LoRa 32 V3 (ESP32-S3)
 * - SX1262 LoRa Radio (915 MHz) via RadioLib
 * - SSD1306 OLED Display (built-in, Wire1)
 * - MCP23017 I2C GPIO Expander (Wire, SDA=41, SCL=42)
 *
 * @author Rajiv Dewan, N2RD
 * @date 2026
 */

// ============================================================================
// INCLUDES
// ============================================================================

#include <Arduino.h>
#include <Wire.h>
#include <SPI.h>
#include <RadioLib.h>
#include <Adafruit_MCP23X17.h>
#include <U8g2lib.h>
#include "config.h"
#include "protocol.h"

// ============================================================================
// GLOBAL OBJECTS
// ============================================================================

// RadioLib SX1262: Module(cs, irq, rst, busy)
SX1262 radio = new Module(SX1262_CS, SX1262_INT, SX1262_RST, SX1262_BUSY);

// OLED: portrait mode (U8G2_R1 = 90° CW → 64×128), SW I2C on dedicated pins
U8G2_SSD1306_128X64_NONAME_F_SW_I2C display(U8G2_R2, I2C_SCL_OLED, I2C_SDA_OLED, OLED_RST);

// GPIO expander
Adafruit_MCP23X17 mcp;

// ============================================================================
// APPLICATION STATE
// ============================================================================

int current_direction  = DIR_NE;
int last_button_pressed = DIR_NE;
int16_t packet_count    = 0;
char cached_rev_pwr[8]  = "--";   // rev power from last PTT reply
char cached_voltage[12] = "--";   // voltage from last direction reply
char cached_current[8]  = "--";   // current from last direction reply
Command current_command = {{0}, 0};
uint8_t last_reply_buffer[255] = {0};
uint8_t last_reply_length = 0;

// ISR flag: set by DIO1 interrupt when a LoRa packet is received
volatile bool replyReceived = false;

// ============================================================================
// FUNCTION PROTOTYPES
// ============================================================================

void init_all_hardware(void);
void build_direction_command(int direction, Command& cmd);
void build_ptt_command(Command& cmd);
void send_and_process_command(const Command& cmd);
void display_direction_reply(const uint8_t* buf, uint8_t len);
void display_power_reply(const uint8_t* buf, uint8_t len);
void handle_button_press(int button);
void handle_ptt_press(void);
void handle_serial_input(void);
void display_message(const char* message);
bool debounce_pin(int pin, int target_level);
int  angle_to_direction(int angle);
void blink_direction_led(int dir);

// ============================================================================
// INTERRUPT SERVICE ROUTINE
// ============================================================================

void IRAM_ATTR onPacketReceived(void) {
    replyReceived = true;
}

// ============================================================================
// INITIALIZATION
// ============================================================================

void init_all_hardware(void) {
    // Serial — USB CDC on ESP32-S3
    Serial.begin(115200);
    // Print dots for 5s so the terminal can connect before important messages
    for (int i = 0; i < 50; i++) {
        Serial.print('.');
        Serial.flush();
        delay(100);
    }
    Serial.println();
    Serial.println("\n========== LoRa Antenna Controller (Heltec V4) Starting ==========");
    Serial.printf("  CPU: %d MHz, Free heap: %d bytes\n",
                  (int)(F_CPU / 1000000), ESP.getFreeHeap());

    // Enable Vext (GPIO36 LOW) to power OLED and MCP23017
    Serial.println("[INIT] Enabling Vext peripheral power...");
    pinMode(VEXT_PIN, OUTPUT);
    digitalWrite(VEXT_PIN, LOW);
    delay(200);
    Serial.println("[INIT] Vext enabled.");

    // PTT pin
    pinMode(PTT_PIN, INPUT_PULLUP);
    Serial.printf("[INIT] PTT pin GPIO%d configured INPUT_PULLUP\n", PTT_PIN);

    // External I2C for MCP23017 (SDA=41, SCL=42 from variants.h)
    Serial.println("[INIT] Starting Wire for MCP23017...");
    Wire.begin();
    Serial.println("[INIT] Wire ready.");

    // RadioLib SX1262 init
    // begin(freq, bw, sf, cr, syncWord, pwr, preambleLen, tcxoVoltage)
    // TCXO on Heltec V3 is 1.8V — required for correct operation
    // set FM pins to output and set them high to enable PA on receive and transmit
    pinMode(SX1262_FEM_EN, OUTPUT);
    pinMode(SX1262_FEM_PA, OUTPUT);
    digitalWrite(SX1262_FEM_EN, HIGH);
    digitalWrite(SX1262_FEM_PA, HIGH);
    
    Serial.printf("[INIT] Starting LoRa radio (CS=%d, INT=%d, RST=%d, BUSY=%d)...\n",
                  SX1262_CS, SX1262_INT, SX1262_RST, SX1262_BUSY);
    //int state = radio.begin(SX1262_FREQ, 125.0, 9, 7,
    //                        RADIOLIB_SX126X_SYNC_WORD_PRIVATE, 20, 8, 1.8);
    int state = radio.begin(SX1262_FREQ, 250.0, 11, 5,
                            RADIOLIB_SX126X_SYNC_WORD_PRIVATE, 20, 8, 1.8);
    if (state != RADIOLIB_ERR_NONE) {
        Serial.printf("[INIT] ERROR: Radio init failed, code %d\n", state);
        while (1) {
            digitalWrite(LED, HIGH); delay(100);
            digitalWrite(LED, LOW);  delay(100);
        }
    }
    // DIO2 drives the RF switch on Heltec V3
    radio.setDio2AsRfSwitch(true);
    // Register ISR for received packets
    radio.setDio1Action(onPacketReceived);
    Serial.printf("[INIT] Radio OK: %.1f MHz, SF9, BW125, CR4/7, TX 20 dBm\n",
                  SX1262_FREQ);

    // OLED init
    pinMode(LED, OUTPUT);
    digitalWrite(LED, HIGH);
    Serial.println("[INIT] Starting OLED display...");
    display.begin();                          // handles reset internally
    display.setContrast(255);
    display.clearBuffer();
    display.setFont(u8g2_font_helvB12_tr);
    display.drawStr(2, 30, "READY!");
    display.sendBuffer();
    Serial.println("[INIT] OLED OK.");
    delay(500);
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

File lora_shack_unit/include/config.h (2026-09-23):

/**
 * @file config.h
 * @brief Configuration and hardware definitions for LoRa Antenna Controller
 *
 * This file contains all hardware pin definitions, radio configuration,
 * and system constants for the controller unit.
 *
 * Hardware: Heltec WiFi LoRa 32 V3 (ESP32-S3, SX1262)
 * Purpose: Remote antenna azimuth control from the shack
 *
 * @author Rajiv Dewan, N2RD
 * @date 2026
 */

#ifndef CONFIG_H
#define CONFIG_H

// ============================================================================
// RADIO CONFIGURATION
// ============================================================================

/** @brief LoRa radio frequency in MHz */
#define SX1262_FREQ 915.0

/** @brief This controller's address */
#define MY_ADDRESS 211

/** @brief Remote phaser unit's address */
#define DEST_ADDRESS 212

// Heltec WiFi LoRa 32 V3 — SX1262 radio pins
#define SX1262_CS   8   ///< LoRa NSS (SS)
#define SX1262_RST  12  ///< LoRa RST
#define SX1262_INT  14  ///< LoRa DIO1 (interrupt)
#define SX1262_BUSY 13  ///< LoRa BUSY
#define SX1262_FEM_EN 2 /// < RF FEM enable 
#define SX1262_FEM_PA 46 /// < RF TX/RX PA Enable
// Power and LED
#define LED          35  ///< Onboard LED (LED_BUILTIN)
#define VEXT_PIN     36  ///< Peripheral power control, active LOW
// PTT input
#define PTT_PIN      3   ///< GPIO3, INPUT_PULLUP, active LOW
// External I2C bus (Wire) — used for MCP23017 (SDA=41, SCL=42 from variants.h)
#define I2C_SDA      41  ///< External I2C SDA
#define I2C_SCL      42  ///< External I2C SCL
// Onboard OLED I2C bus (Wire1) — SSD1306 on dedicated pins
#define I2C_SDA_OLED 17  ///< OLED SDA
#define I2C_SCL_OLED 18  ///< OLED SCL
#define OLED_RST     21  ///< OLED RST

// Transmitting 32B at SF 11 can take upto 2.2 seconds.  Use a longer timeout to be safe.
/** @brief Timeout waiting for reply from phaser (milliseconds) */
#define REC_TIMEOUT 5000

/** @brief Longer timeout for power/telemetry query — phaser needs ~100 ms for ADC sampling */
#define REC_TIMEOUT_POWER 5000

// ============================================================================
// GPIO EXPANDER (MCP23017) CONFIGURATION
// ============================================================================

/** @brief I2C address of MCP23017 GPIO expander (default address) */
#define MCP_I2C_ADDRESS 0x20

/** @brief Number of buttons/directions */
#define NUM_DIRECTIONS 8

/** @brief Button pins on MCP (pins 0-7) */
#define BUTTON_PIN_START 0
#define BUTTON_PIN_END 7

/** @brief LED pins on MCP (pins 8-15) */
#define LED_PIN_START 8
#define LED_PIN_END 15

// ============================================================================
// OLED DISPLAY CONFIGURATION
// ============================================================================

/** @brief I2C address of SH1106 OLED display */
#define OLED_I2C_ADDRESS 0x3C

/** @brief OLED display width in pixels */
#define SCREEN_WIDTH 128

/** @brief OLED display height in pixels */
#define SCREEN_HEIGHT 64

// ============================================================================
// INPUT/OUTPUT PINS
// ============================================================================

/** @brief Debounce delay for PTT input (milliseconds) */
#define DEBOUNCE_DELAY_MS 25

// ============================================================================
// ANTENNA DIRECTIONS
// ============================================================================

/** @brief Antenna direction enumeration */
enum Direction {
    DIR_NE = 0,   /**< Northeast (045°) */
    DIR_E = 1,    /**< East (090°) */
    DIR_SE = 2,   /**< Southeast (135°) */
    DIR_S = 3,    /**< South (180°) */
    DIR_SW = 4,   /**< Southwest (225°) */
    DIR_W = 5,    /**< West (270°) */
    DIR_NW = 6,   /**< Northwest (315°) */
    DIR_N = 7     /**< North (000°) */
};

/** @brief Direction names for display */
static const char* DIRECTION_NAMES[] = {
    "NE", "E", "SE", "S", "SW", "W", "NW", "N"
};

/** @brief Direction angles in degrees */
static const int DIRECTION_ANGLES[] = {
    45, 90, 135, 180, 225, 270, 315, 0
};

/**
 * @brief Physical MCP23017 pin layout starts at N=0 going clockwise:
 *   pin 0=N, 1=NE, 2=E, 3=SE, 4=S, 5=SW, 6=W, 7=NW
 * These tables translate between software direction index and hardware pin index.
 */
/** @brief Software direction index → hardware pin offset (0-7) */
static const int DIR_TO_HW[8] = {1, 2, 3, 4, 5, 6, 7, 0};
/** @brief Hardware pin offset (0-7) → software direction index */
static const int HW_TO_DIR[8] = {7, 0, 1, 2, 3, 4, 5, 6};

// ============================================================================
// PROTOCOL CONFIGURATION
// ============================================================================

/** @brief Maximum length of command buffer */
#define MAX_COMMAND_LEN 7

/** @brief Maximum length of reply buffer */
#define MAX_REPLY_LEN 256
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

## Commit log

2026-09-23 ready for sharing
    [Bottom.stl, Bracket.stl, Top.stl]
2026-09-23 Create README for LoRa Antenna Controller project
    Add initial README with project overview and structure.
2026-10-01 README enhanced to provide comprehensive construction details
    [Phaser_Heltec_V21-B_Cu.gbl, Phaser_Heltec_V21-B_Mask.gbs, Phaser_Heltec_V21-B_Paste.gbp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]
